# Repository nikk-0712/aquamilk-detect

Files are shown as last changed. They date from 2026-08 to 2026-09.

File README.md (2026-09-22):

# Aqua Milk Detect

**Milk purity in seconds.**

A low-cost, portable IoT + edge-ML device that classifies a milk sample as **Pure**,
**Water-adulterated**, **Detergent-adulterated** or **Starch-adulterated** — or honestly
says **Uncertain** — in a few seconds, using six sensors and an on-device SVM. It flushes
its own chamber between tests, shows the verdict on a TFT, and serves its own Wi-Fi
dashboard with no internet involved.





SDGs: 3 (Good Health), 9 (Industry & Innovation), 12 (Responsible Consumption).

---

## How the whole thing fits together

```mermaid
flowchart LR
  subgraph browser["Browser (GitHub Pages, HTTPS)"]
    FLASH["Flash<br/>ESP Web Tools"]
    CAL["Calibrate<br/>Web Serial"]
    COL["Collect<br/>Web Serial → CSV"]
  end
  subgraph device["ESP32 device"]
    S1["01_calibration"]
    S2["02_collection"]
    S3["03_deployment<br/>SVM + dashboard"]
  end
  TRAIN["training/train.py<br/>SVM + report"]

  FLASH -->|.bin| S1 & S2 & S3
  CAL <-->|JSON over USB| S1
  COL <-->|JSON over USB| S2
  COL -->|labelled CSV| TRAIN
  TRAIN -->|model.h + scaler.h| S3
  S3 -->|own Wi-Fi, HTTP| PHONE["Phone / laptop"]
```

Four stages, in order:

| Stage | You do | Where |
|---|---|---|
| 1 · Calibrate | Zero and span every sensor; constants are saved in the ESP32's NVS | [01_calibration](01_calibration/) |
| 2 · Collect | Capture labelled pure/spiked samples; the browser writes the CSV | [02_collection](02_collection/) |
| 3 · Train | Fit the SVM, read the honest report, export two headers | [training](training/) |
| 4 · Deploy | Flash the finished tester; it runs standalone | [03_deployment](03_deployment/) |

The web app that drives stages 1, 2 and the flashing lives in [web/](web/) and is
published to GitHub Pages by CI. Shared sensor code lives once in
[libs/AquaMilkSensors](libs/AquaMilkSensors) — all three firmwares compile the same file.

---

## Hardware

ESP32 DevKit V1 (38-pin, ESP32-WROOM-32), Arduino core — not ESP-IDF.

| Function | Part | Interface |
|---|---|---|
| pH | Analog pH kit, BNC probe | analog → ADC1 |
| TDS / conductivity | DFRobot Gravity Analog TDS | analog → ADC1 |
| Turbidity | Turbidity sensor + module | analog → ADC1 |
| Colour | TCS34725 RGB + Clear | I²C |
| Temperature | DS18B20 waterproof | OneWire |
| Display | 1.8" ST7735 TFT, 128×160 | SPI |
| Pump | 6 V peristaltic dosing pump | via 3.3 V relay module |
| Control | Browser dashboard (Wi-Fi) | — |
| Power | 12 V 1.5 A adapter + LM2596 buck ×2 | — |

### Pin map (final — used by all three firmwares)

Defined once in [`libs/AquaMilkSensors/src/pins.h`](libs/AquaMilkSensors/src/pins.h).

| Signal | GPIO | Notes |
|---|---|---|
| pH analog in | **36** | VP, ADC1_CH0, input-only |
| TDS analog in | **39** | VN, ADC1_CH3, input-only |
| Turbidity analog in | **34** | ADC1_CH6, input-only |
| TCS34725 SDA / SCL | **21 / 22** | I²C |
| DS18B20 data | **4** | 4.7 kΩ pull-up to 3V3 |
| TFT SCLK / MOSI | **18 / 23** | VSPI |
| TFT CS / DC / RST | **5 / 2 / 15** | DC/RST on strapping pins — pull the DevKit to flash, then reseat |
| TFT backlight | 3V3 | (GPIO32 left free for PWM dimming) |
| Pump (relay IN) | **25** | Digital output, active-HIGH |
| (GPIO27 free) | — | TTP223 touch pad removed — browser-controlled |

Free for later: 13, 14, 26, 32, 33, 35 (35 input-only). Avoid GPIO12 (boot strapping).

### Two wiring things that will bite you

**1 · The analog sensors can exceed 3.3 V.** The ESP32's ADC tops out at ~3.3 V, but the
turbidity module swings to 4.5 V and the pH board can approach 5 V. Put a **resistor
divider** (2:1 is fine, e.g. two 10 kΩ) on those channels, or run the boards from 3.3 V.
Then tell the firmware the ratio you actually built — `div_ph`, `div_turb`, `div_tds` on
the Calibrate page — because everything downstream reports millivolts *at the sensor*.
All three analog channels are on **ADC1** deliberately: ADC2 does not work while Wi-Fi is
on, and stage 3 needs Wi-Fi.

**2 · The pump is switched by a 3.3 V relay module.** It is driven straight from GPIO25 —
the module's onboard transistor and flyback do the work, so no 2N2222 level-shifter is
needed:

```
GPIO25 → relay IN      pump +6 V feed → relay COM/NO
3V3    → relay VCC
GND    → relay GND
```

This module is **active-HIGH** (GPIO HIGH = pump ON), so `PUMP_ACTIVE_LOW` defaults to
`false` in [`sensors.h`](libs/AquaMilkSensors/src/sensors.h). Got an active-LOW board (pump
runs at idle)? Set that flag `true` and rebuild. **Never PWM a relay** — drive it as a
plain digital output. A **1N4007 across the pump** (band → +6 V) is optional insurance
against contact arcing.

### Power

```mermaid
flowchart LR
  ADP["12 V 1.5 A adapter"] --> B1["LM2596 → 6 V"] --> PUMP["6 V pump<br/>1N4007 across it"]
  ADP --> B2["LM2596 → 5 V"] --> ESP["ESP32 5V pin"]
  ESP --> R3["3V3 rail"] --> SENSORS["TFT · TCS34725 · DS18B20"]
  ESP -.->|"GPIO25 → 3.3 V relay"| PUMP
```

Full connection-by-connection list and the power budget: [docs/wiring.md](docs/wiring.md).
Enclosure and test-chamber dimensions: [docs/enclosure.md](docs/enclosure.md), printable
model in [hardware/enclosure.scad](hardware/enclosure.scad).

---

## Use it

### Flash

Easiest path: open the Pages site in **desktop Chrome or Edge** → **Flash** → pick a
firmware. That is why CI exists; the `.bin` files are published next to the site. You
never tell the page a COM port — Chrome shows its own serial-device picker when you click
Install, and you choose your board there (`USB-SERIAL CH340 (COM7)` or similar). If the
board is not in that list it is a driver or cable problem: install the CH340/CP2102
driver and use a data-capable cable, not a charge-only one.

From a clone instead. Find your port first — **`COM5` below is only an example**:

```bash
arduino-cli board list
```

```bash
arduino-cli compile --fqbn esp32:esp32:esp32:PartitionScheme=huge_app --libraries libs 01_calibration
```

```bash
arduino-cli upload -p COM5 --fqbn esp32:esp32:esp32:PartitionScheme=huge_app 01_calibration
```

`--libraries libs` is what resolves `#include <sensors.h>`. Using the Arduino IDE? Copy
`libs/AquaMilkSensors` into your `Arduino/libraries/` folder once. Library and core
versions are pinned in
[`build-firmware.yml`](.github/workflows/build-firmware.yml).

### Calibrate, then collect

Walkthroughs live with the firmware: [stage 1](01_calibration/README.md),
[stage 2](02_collection/README.md). Order matters — the collection firmware reads the
constants stage 1 stored, and the model is only as good as the calibration underneath it.

### Train

```bash
python -m venv .venv
.venv/Scripts/activate  # macOS/Linux: source .venv/bin/activate
python -m pip install -r training/requirements.txt
```

```bash
python training/train.py
```

Reads `training/data/*.csv`, prints accuracy, macro-F1, per-class precision/recall, the
full confusion matrix, a threshold sweep and a limitations section, then writes `model.h`
and `scaler.h`. Copy both into `03_deployment/` and reflash. Details and the honest
reading of those numbers: [training/README.md](training/README.md).

Want to see the pipeline run before you own any data? `python training/train.py --synthetic`.

### Run the finished device

Power it. It brings up its own Wi-Fi — **AquaMilk-XXXX**, password shown on the TFT — and
serves the dashboard at **http://192.168.4.1**. It runs a **captive portal**, so the moment
your phone joins the network the "Sign in to Wi-Fi" browser pops open on the dashboard
automatically — no need to type the address. (If your phone shows it in the cut-down captive
window, tap "open in browser" for the full live view.) Point it at your own network in
Settings and it also answers at `http://aquamilk.local`.

Everything is controlled from the dashboard — **Run test**, **Flush**, **Tare**,
**Re-check calibration**, **Settings**, **Wi-Fi**, and **Factory reset**. The TTP223
touch pad and its gestures were removed, so there is no on-device menu or sleep.

A test averages ~3 s, shows the class with a confidence ring, gives the binary
pure-vs-adulterated headline plus the two sensors that drove the decision, logs the
result, then flushes for ~5 s. Below the confidence threshold (default 0.60, adjustable)
it reports **Uncertain** rather than guessing.

---

## Repo layout

```
aquamilk-detect/
├── PROJECT_CONTEXT.md      the spec; it wins any disagreement with this README
├── 01_calibration/         stage 1 sketch + walkthrough
├── 02_collection/          stage 2 sketch + capture workflow
├── 03_deployment/          stage 3 sketch, SVM inference, dashboard, model headers
├── libs/AquaMilkSensors/   shared sensors, calibration, pump, display, feature contract
├── web/                    the GitHub Pages app (+ firmware/ filled by CI)
├── training/               SVM trainer, notebook, report
├── tools/                  build_dashboard.py (gzips the device dashboard into PROGMEM)
├── docs/                   wiring detail, original build prompts
└── .github/workflows/      build firmware · deploy Pages
```

## CI

One workflow, [`build-and-deploy.yml`](.github/workflows/build-and-deploy.yml): regenerate
`03_deployment/dashboard.h` (failing if the committed copy was stale), compile all three
sketches with pinned tool/core/library versions, stage the merged `.bin`s and ESP Web
Tools manifests into `web/firmware/`, then publish `web/` to Pages. It fails loudly if any
sketch does not compile, and the job summary warns when the deployment build still carries
the placeholder model.

The binaries are **not committed** — they reach Pages as an artifact. arduino-cli pads a
merged image to the full 4 MB flash size, so committing three of them added ~12 MB to git
on every run; going via the artifact also means CI needs no write access to the repo and
leaves no bot commits. The trade-off: a plain `git clone` gives you no prebuilt binaries,
so build them yourself or grab them from the live site.

Live at **https://nikk-0712.github.io/aquamilk-detect/**. Pages is set to Source:
GitHub Actions.

## Honest limits

- `03_deployment/model.h` ships as a **placeholder**. Until you train, every test
  correctly reports "Uncertain — no model on device".
- The model learns raw sensor millivolts from *your* device with *your* calibration.
  Recalibrating, swapping a probe or moving to another board shifts those numbers.
- Starch is the hardest class — it pushes turbidity the same direction fat does.
- Specific gravity comes from grams in a fixed-volume chamber, with an approximate
  thermal-expansion correction. The constants are tunable in `sensors.cpp` and
  `training/utils.py`; they are one place real hardware will need tuning.
- This is a screening instrument, not a laboratory assay. It tells you a sample looks
  wrong and deserves a real test.

MIT licensed.

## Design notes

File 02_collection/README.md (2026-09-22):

# Stage 2 — Data collection firmware

Captures labelled training samples and streams them to the **Collect** page of the web
app, which builds the CSV in the browser. No Wi-Fi, no SD card. Sensor code and
calibration are inherited from Stage 1 — same `libs/AquaMilkSensors`, same NVS
namespace, so **calibrate before you collect**.

## Flash it

Web app: **Flash → Collection firmware** (Chrome asks which device; no port to configure).
Or, with your own port from `arduino-cli board list` in place of the example `COM5`:

```bash
arduino-cli compile --fqbn esp32:esp32:esp32 --libraries libs 02_collection
```

```bash
arduino-cli upload -p COM5 --fqbn esp32:esp32:esp32 02_collection
```

## Capture workflow

1. Open **Collect**, connect the device.
2. Fill in the labels: milk type (cow / buffalo / toned), adulterant (pure / water /
   detergent / starch), level %, and the free-text **source** (which dairy, shop or
   person the milk came from). The labels live in the browser — the device never sees
   them, it only measures.
3. Pour the sample into the chamber. Watch the live values settle.
4. Hit **Capture**. The device averages for `avg_ms` (default 3 s), emits one
   `{"t":"sample",…}` record, then auto-flushes for `flush_ms` (default 5 s) and sends
   `{"t":"flush_done"}`. One capture = one CSV row; there is no auto-batching.
5. Repeat. The browser keeps the running table, per-class counts, and the CSV export.

Capture is refused with `{"t":"ack","ok":false,"msg":"busy"}` while an average or a
flush is still running, so you cannot accidentally sample into a flushing chamber.

**Aim for balance.** The per-class counts in the web app exist because an SVM trained
on 90 pure and 6 starch samples will simply learn to say "pure". Collect across more
than one source too — a model trained on one dairy's milk mostly learns that dairy.

## Sample record fields

Names match the CSV schema (`PROJECT_CONTEXT.md` §5) exactly, so the browser maps them
straight into a row:

| Field | Meaning |
|---|---|
| `temp_c` | DS18B20 °C |
| `ph_raw_mv` | pH board output, millivolts, divider-corrected |
| `tds_raw_mv` | TDS board output, millivolts |
| `turbidity_raw_mv` | Turbidity board output, millivolts |
| `color_r`, `color_g`, `color_b`, `color_clear` | TCS34725 raw channels |
| `ph_sd`, `tds_sd`, `turbidity_sd`, `density_sd`, `temp_sd` | Standard deviation across the averaging window |
| `sg` | Derived temperature-corrected specific gravity (this is model feature 3) |
| `n` | Reads that survived outlier trimming (top/bottom 10 % dropped) |
| `ts`, `count` | Device millis, session sample counter |

The `*_sd` columns are the honest-sample check: if `density_sd` is large someone
knocked the bench, if `turbidity_sd` is large there were bubbles. Retake that sample
rather than training on it.

## Commands

| Command | Effect |
|---|---|
| `{"cmd":"capture"}` | Average, emit one sample, auto-flush |
| `{"cmd":"flush","ms":5000}` | Flush now |
| `{"cmd":"tare"}` | Re-zero the empty chamber |
| `{"cmd":"set","key":"avg_ms","val":3000}` | Averaging window (200–20000 ms) |
| `{"cmd":"set","key":"flush_ms","val":5000}` | Flush duration (0–60000 ms) |
| `{"cmd":"reset_counter"}` | Clear the on-device session counter |

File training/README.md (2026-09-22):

# training/ — SVM trainer

Turns the CSVs you collected into `model.h` + `scaler.h` for the deployment firmware,
plus an evaluation report you can defend in a viva.

## Run it

```bash
python -m venv .venv
.venv/Scripts/activate  # macOS/Linux: source .venv/bin/activate
python -m pip install -r training/requirements.txt
```

Put the CSVs exported from the web app's **Collect** page into `training/data/`, then:

```bash
python train.py
```

Smoke-test the whole pipeline before you own any real data:

```bash
python train.py --synthetic
```

Check the maths itself (feature transform + the probability path the firmware runs):

```bash
python utils.py
```

Useful flags: `--chamber-ml` (must match the value stored on the device — the Calibrate
page shows it), `--test-size`, `--seed`, `--min-per-class`, `--no-export`.

## What comes out

| File | What it is |
|---|---|
| `model.h` | The trained SVM: support vectors, dual coefficients, intercepts, Platt `probA_`/`probB_` |
| `scaler.h` | `FEAT_MEAN[9]`, `FEAT_SCALE[9]`, and the recommended `CONF_THRESHOLD` |
| `report/report.txt` | The whole run as text: CV score, held-out metrics, confusion matrix, threshold sweep, limitations |
| `report/confusion.png` | Confusion matrix |
| `report/threshold.png` | Accuracy vs coverage as the Uncertain cut-off moves |
| `report/metrics.json` | Every number, machine-readable |
| `pipeline.joblib` | Fitted scaler + model, if you want to keep exploring in Python |

Copy the two headers into the firmware and reflash:

```bash
cp training/model.h training/scaler.h 03_deployment/
```

Pushing those changed headers re-triggers the firmware build in CI, so the `.bin` the
web app offers gets your model automatically.

## Features

Exact order, matching `libs/AquaMilkSensors/src/features.h`:

```
[ph, tds, turbidity, temperature, color_r, color_g, color_b, color_clear]
```

`raw_to_features()` in `utils.py` is the single definition of that mapping. It does no
transforms: every feature is fed as the raw millivolts, temperature and raw colour
counts the CSV already holds. (The density/load-cell feature was removed.)

That is a deliberate choice. The CSV only stores raws, so training on raws means the
firmware and the trainer cannot disagree about what a feature *is*, and re-calibrating
the pH probe does not silently invalidate a trained model. `StandardScaler` makes the
units irrelevant to the SVM anyway. Calibrated pH / ppm / NTU still exist on the device —
for humans to read, not for the model to consume.

## Why not micromlgen

The spec suggested `micromlgen.port()`. Its SVM port emits `predict()` only, and this
product needs a **probability**, because anything below the confidence threshold has to
come out as "Uncertain". A model that can only say "starch" with no confidence attached
cannot implement that rule.

So the exporter writes scikit-learn's own `SVC` internals, and
`03_deployment/svm_infer.h` runs libsvm's actual procedure: one-vs-one decision values →
Platt sigmoids → Chu & Lin pairwise coupling. Before writing `model.h`,
`verify_probabilities()` re-implements that same path in numpy and asserts it reproduces
`clf.predict_proba` (typically within ~2e-3, the coupling loop's own tolerance). If it
ever disagrees, the run fails and nothing is exported — a wrong confidence would be
worse than no model, since the whole Uncertain mechanism rests on it.

## Reading the report honestly

- **Report the confusion matrix, not the accuracy.** With a few dozen rows per class,
  accuracy moves several points just from reshuffling the split.
- **Starch is the hard class.** It pushes turbidity the same direction fat does, so it
  gets confused with pure milk more than water or detergent do. If starch recall is much
  worse than the rest, that is the expected failure, not a bug.
- **Balance matters more than volume.** The trainer warns when one class is more than
  3× another, and when every row shares a single `source` or `milk_type` — a model
  trained on one dairy mostly learns that dairy.
- **The binary headline** (pure vs adulterated) is always reported alongside the
  4-class numbers, because it is the number a user actually acts on.
- `--synthetic` runs are labelled as synthetic in both the console output and
  `metrics.json`. Those numbers describe a random generator, not milk.

## data/

`SYNTHETIC_sample.csv` is generated, clearly marked, and exists so `python train.py`
works on a fresh clone. Delete it once you have real data — otherwise it will be
concatenated into your dataset and quietly train on invented numbers.

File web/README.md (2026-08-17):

# web/ — the GitHub Pages app

Static single-page app: **Home · Flash · Calibrate · Collect · Run**. No build step, no
bundler, no backend — the files here are exactly what gets served.

```
web/
├── index.html                 all five sections
├── app.js                     routing + Calibrate/Collect logic
├── serial.js                  Web Serial transport for the §8 JSON protocol
├── app.css                    the app's styles
├── design/tokens.css          shared design variables (the device dashboard mirrors these)
├── logo.svg                   the mark
└── firmware/                  .bin files + ESP Web Tools manifests (CI fills these)
```

## Run it locally

Web Serial and browser flashing need a **secure context**, and `localhost` counts:

```bash
python -m http.server 8000 --directory web
```

Then open <http://localhost:8000>. Opening `index.html` as a `file://` URL will not work —
ES modules and Web Serial both refuse that.

## What needs what

| Page | Needs |
|---|---|
| Home, Run | Any browser, any device |
| Flash | Desktop Chrome/Edge + HTTPS (or localhost) — ESP Web Tools |
| Calibrate, Collect | Desktop Chrome/Edge + HTTPS (or localhost) — Web Serial |

The app detects a missing Web Serial API and says so on the Home page rather than
failing silently when you click Connect.

## firmware/

`*-manifest.json` point at `calibration.bin`, `collection.bin`, `deployment.bin`. The
[build-and-deploy workflow](../.github/workflows/build-and-deploy.yml) compiles all three
sketches, drops the **merged** binaries here (merged = bootloader + partition table + app
in one image, which is why the manifest offset is 0), stamps the real version into the
manifests, and ships the folder to Pages as an artifact.

The `.bin` files are deliberately **not in git** — each is 4 MB of padded flash image, so
committing them cost ~12 MB per CI run. That means a fresh clone has manifests pointing at
binaries that only exist on the deployed site: serving `web/` locally will show the Flash
buttons, but they cannot install until you either run the workflow or build locally and
copy the merged `.bin`s in yourself.

## Notes on the code

- **No localStorage.** Collected rows live in a JavaScript array and leave via the
  Export CSV button. Reloading the tab loses unexported rows — that is deliberate;
  half-finished datasets silently resurrecting is worse.
- **CSV columns** are built in `app.js:COLUMNS`, matching `PROJECT_CONTEXT.md` §5 exactly
  so the Python trainer can read the file with no massaging.
- **Two independent serial links**, one per page. Calibrate and Collect run different
  firmwares, so there is no case where both are connected to the same device at once.
- **esp-web-tools is vendored**, not loaded from a CDN: `web/vendor/esp-web-tools/`
  holds v10.4.0's bundled `dist/web` (Apache-2.0, `LICENSE` included). It started as a
  pinned unpkg URL, which broke the Flash page twice over — the pinned version did not
  exist, and a CDN fetch is blockable by extensions. Nothing external is fetched now.
  To update: `npm pack esp-web-tools@<version>`, then copy `dist/web/*.js` + `LICENSE`
  into that folder.
- **The Run page is a launcher, not a dashboard.** This site is HTTPS; the device serves
  plain HTTP on a private IP, and browsers block that mix. So the live dashboard lives on
  the device (`03_deployment/dashboard.html`) and shares this app's design tokens.

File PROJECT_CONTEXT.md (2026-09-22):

# Aqua Milk Detect — PROJECT CONTEXT (single source of truth)

> Every agent building any part of this project MUST read this file first and treat it as authoritative. If a prompt and this file disagree, this file wins. Keep the same names, pins, colors, and schema everywhere.

**Tagline:** *Milk purity in seconds.*
**One line:** A low-cost, portable IoT + edge-ML device that classifies a milk sample as **Pure / Water-adulterated / Detergent-adulterated / Starch-adulterated** (or **Uncertain**) in seconds, using multi-sensor data and an on-device SVM, with a self-cleaning flush and an elegant web + on-device UI.

SDGs: 3 (Good Health), 9 (Industry/Innovation), 12 (Responsible Consumption).

---

## 1. System overview (three stages, one repo)

The system is delivered as **three separate Arduino firmwares** plus **one web app**, **one Python trainer**, and **CI to build + host**:

| Stage | Folder | Runs on | Talks to browser via | Purpose |
|---|---|---|---|---|
| 1. Calibration & test | `01_calibration/` | ESP32 | **USB Web Serial** | Read + calibrate each sensor and all-at-once |
| 2. Data collection | `02_collection/` | ESP32 | **USB Web Serial** | Capture labelled samples → CSV in browser |
| 3. Deployment | `03_deployment/` | ESP32 | **Wi-Fi (SoftAP / STA)** + TFT | Run the trained SVM, show verdict, self-flush |
| Web app | `web/` | GitHub Pages | — | Flash firmware + Calibrate + Collect UIs |
| Trainer | `training/` | User PC (Python) | — | Train SVM from CSV → export `model.h` |
| CI | `.github/workflows/` | GitHub Actions | — | Build `.bin`s + deploy `web/` to Pages |

**Data/ML loop:** Stage 2 collects labelled CSV → Python trainer makes `model.h` → drop into Stage 3 → deploy.

---

## 2. Hardware (FINAL bill of materials)

**MCU:** ESP32 DevKit V1, 38-pin, ESP32-WROOM-32 (user owns). Framework: **Arduino (arduino-esp32 core)**. NOT ESP-IDF.

**Sensors & modules:**
| Function | Part | Interface | Notes |
|---|---|---|---|
| pH | Analog pH sensor kit (Industrial Grade Analog pH, BNC probe) | Analog → ADC1 | Detergent (alkaline) flag; output may reach ~3–5 V → **see ADC note** |
| TDS / conductivity | DFRobot Gravity Analog TDS (genuine) | Analog → ADC1 | Water/detergent dilution; library `GravityTDS` |
| Turbidity | Turbidity Sensor With Module | Analog → ADC1 | Starch/suspended solids; output 0–4.5 V → **needs divider** |
| Colour | TCS34725 RGB+Clear | I²C | R,G,B,Clear channels as features |
| Temperature | DS18B20 waterproof (genuine chip, 1 m) | OneWire | Temp compensation for pH/TDS/density |
| Display | 1.8" TFT ST7735, 128×160 | SPI | On-device verdict + status |
| Pump | 6 V peristaltic dosing pump | via relay | Auto-flush chamber with distilled water |
| Pump switch | **3.3 V relay module** (user owns) | GPIO (digital) | Driven direct from GPIO25 — see §4 |
| Flyback | 1N4007 diode (optional) | across pump | Cheap insurance against contact arcing |
| Power step-down | LM2596 buck | — | 12 V → 6 V (pump) and 5 V/3.3 V (logic) |
| Power source | 12 V 1.5 A adapter (user owns) | — | 18 W, ample |
| Control | **Browser dashboard** over Wi-Fi | — | No touch pad, no LEDs |
| Fluidics | Silicone tube 1 m + user's reservoir & waste cup | — | Flush plumbing |

**User-owned / not purchased:** ESP32, 3.3 V relay module, 12 V 1.5 A adapter, 1N4007 diode (optional), jumper wires, breadboard.
**User to source separately:** enclosure + test chamber, distilled water, (optional, cheap) pH 4/7 buffer sachets.

**Purchase split (both free-shipping > ₹999, ₹0 shipping):**
- **Robu.in:** pH kit (₹1,975) + DS18B20 genuine-chip (₹89).
- **Robocraze:** DFRobot TDS, turbidity, 6 V pump, TCS34725, 1.8" TFT, LM2596, silicone tube.
- Total to buy ≈ **₹4,969** (under ₹5,000 budget). Owned parts saved ≈ ₹600.

---

## 3. Pin map (ESP32-WROOM-32, 38-pin) — FINAL

Use these exact pins in all firmwares.

| Signal | GPIO | Notes |
|---|---|---|
| pH analog in | **36** (VP, ADC1_CH0) | input-only, ADC1 |
| TDS analog in | **39** (VN, ADC1_CH3) | input-only, ADC1 |
| Turbidity analog in | **34** (ADC1_CH6) | input-only, ADC1 |
| TCS34725 SDA | **21** | I²C |
| TCS34725 SCL | **22** | I²C |
| DS18B20 data | **4** | OneWire + 4.7 kΩ pull-up to 3V3 |
| TFT SCLK | **18** | VSPI |
| TFT MOSI | **23** | VSPI |
| TFT CS | **5** | strapping pin — fine as output |
| TFT DC | **2** | strapping pin — pull the DevKit from its socket to flash, then reseat |
| TFT RST | **15** | strapping pin — pull the DevKit from its socket to flash, then reseat |
| TFT BL (backlight) | tie to 3V3 (or **32** for dim) | |
| Pump (relay IN) | **25** | Plain digital output (active-HIGH) |
| (GPIO27 free) | — | TTP223 removed — device controlled from the browser |

**ADC rules (critical):**
- All three analog sensors are on **ADC1** because **ADC2 is unusable while Wi-Fi is on**.
- ESP32 ADC is 12-bit, 0–3.3 V. **Any sensor board that can output > 3.3 V (turbidity 0–4.5 V; pH board can approach 5 V) MUST go through a resistor voltage divider** (e.g. 2:1) or the board must be run at 3.3 V. Document the divider in the wiring README. Calibration maps raw ADC → sensor value, so exact divider ratio is captured during calibration.
- Use `analogReadMilliVolts()` / attenuation `ADC_11db` for the widest linear range; average many samples.

Free/unused pins for future use: 13, 14, 26, 33, 35 (35 input-only). Avoid GPIO12 (strapping, boot).

---

## 4. Power & pump switching (3.3 V relay)

Power: 12 V adapter → LM2596 #1 set to **6 V** for the pump; logic runs from **5 V/USB or a second LM2596 at 5 V**. ESP32 from 5 V pin or USB.

Pump switching uses a **3.3 V relay module** driven straight from the ESP32 — the module's onboard driver transistor and flyback do the work, so GPIO25 sources almost no current and no level-shifter is needed. Firmware therefore:
- Drives the pump as a **plain digital output on GPIO25** (`pinMode(OUTPUT)` + `digitalWrite`). **Never PWM a relay** — the coil would chatter. Pump control is on/off only.
- Uses a `PUMP_ACTIVE_LOW` compile-time flag for the module's polarity. **This build's module is active-HIGH (GPIO HIGH = pump ON), so the flag defaults to `false`.** For the common opto-isolated boards that energize on LOW, set it `true`.
- Wiring: `GPIO25 → relay IN`, `3V3 → relay VCC`, `GND → relay GND`, and the pump's +6 V feed through the relay `COM`/`NO` contacts. A **1N4007 across the pump** (band → +6 V) is optional insurance against contact arcing.

---

## 5. Data schema (CSV) — FINAL

One captured sample = one CSV row. Store **raw** sensor values (so features can be re-derived) plus labels & metadata.

```
timestamp_iso, milk_type, adulterant, level_pct, source,
temp_c, ph_raw_mv, tds_raw_mv, turbidity_raw_mv,
color_r, color_g, color_b, color_clear
```

- `milk_type` ∈ {cow, buffalo, toned}
- `adulterant` ∈ {pure, water, detergent, starch}
- `level_pct` ∈ {0, 5, 10, 20, 30, …} (0 for pure)
- `source` = free text (dairy / shop / person / place) — **user's tagging field**
- `*_raw_mv` = averaged ADC millivolts; color_* = TCS34725 channels.
- CSV is created and saved **in the browser** (no server, no SD card).

**Feature vector for the model (≈10):** `ph, tds, turbidity, density(temp-corrected specific gravity), temperature, color_r, color_g, color_b, color_clear` (+ optionally derived ratios). Fit a `StandardScaler`; export scaler constants alongside the model.

---

## 6. Model & inference

- **Algorithm:** SVM (scikit-learn). Compare **linear vs RBF** via `GridSearchCV` + stratified k-fold; pick best by macro-F1.
- **Classes:** `pure, water, detergent, starch`. Also compute a **binary headline** (pure vs adulterated).
- **Uncertain / reject:** use `predict_proba` (Platt) — if top-class probability `< threshold` (default **0.60**, tunable in the deployment Settings), output **Uncertain**. Optionally a one-class outlier guard on "pure".
- **Export:** `micromlgen` → `model.h` (C++), plus a `scaler.h` (means/scales) → included by `03_deployment`. Inference on-device is microseconds.
- **Honesty:** trainer must print accuracy, macro-F1, full **confusion matrix**, per-class precision/recall, and note that starch is the hardest class. Report both multiclass and binary numbers.

---

## 7. Interaction — browser dashboard (deployment)

**No touch pad, no LEDs.** All control and feedback is on the **TFT** (status + verdict) and the **web dashboard** served over Wi-Fi. Dashboard controls: **Run test**, **Flush**, **Tare**, **Re-check calibration**, **Settings** (threshold / flush ms / avg ms), **Wi-Fi**, and **Factory reset**.

Test flow: sample in → **Run test** on the dashboard → TFT shows "Reading…" (average ~3 s) → verdict + confidence → **auto-flush ~5 s** → ready. Uncertain → amber "Uncertain — retest".

---

## 8. Connectivity & protocol

- **USB Web Serial (Stages 1 & 2):** newline-delimited **JSON**. Baud 115200.
  - Device→browser: `{"t":"reading","ph":..,"tds":..,"turb":..,"temp":..,"dens":..,"r":..,"g":..,"b":..,"c":..,"ts":..}`
  - Browser→device: `{"cmd":"capture"}` · `{"cmd":"calibrate","sensor":"ph","point":7.0}` · `{"cmd":"tare"}` · `{"cmd":"flush","ms":5000}` · `{"cmd":"set","key":"..","val":..}`
  - Device acks: `{"t":"ack","cmd":"..","ok":true,"msg":".."}`
- **Wi-Fi (Stage 3):** default **SoftAP** SSID `AquaMilk-XXXX` (XXXX = last 2 bytes of MAC), password shown on TFT; device serves its own dashboard at `http://192.168.4.1` with a **WebSocket** for live data. Optional **STA** (join lab Wi-Fi, creds set in Settings) reachable at **`aquamilk.local`** via mDNS. HTTP only on-device (that's why Run is device-served — an HTTPS page can't call an HTTP device: mixed content).

---

## 9. Design language (Apple-grade) — shared by web app AND device dashboard

**Use the installed Apple design skill for all UI work.** Both the GitHub-hosted app and the ESP32-served Run page share this system.

- **Type:** `-apple-system, "SF Pro Text", "SF Pro Display", system-ui, sans-serif`. Big rounded titles, strong hierarchy, tight tracking on large text.
- **Theme:** **light + dark, auto (`prefers-color-scheme`), default light.**
- **Palette:**
  - Accent (aqua-teal): `#0FB5C9` (darker `#0A8FA3`)
  - Backgrounds: light `#F5F5F7`, dark `#000000` — Apple's own neutrals; they read warmer
    and calmer than the blue-tinted `#F5F7FA` / `#0B0F14` this started with
  - Text: light `#1D1D1F`, dark `#F5F5F7`; secondary `#86868B` / `#A1A1A6`
  - Cards/surfaces: light `#FFFFFF`, dark `#1D1D1F`, with subtle translucency/blur (frosted) where tasteful
  - **Result semantics:** Pure = green `#34C759` · Adulterated = red `#FF3B30` · Uncertain = amber `#FF9F0A` (Apple system colors)
- **Shape & motion:** 16–20 px corner radius, soft layered shadows, 8-pt spacing grid, 200–300 ms ease transitions, gentle spring on the result reveal, circular **confidence ring** (SVG). SF-style segmented controls, toggles, large tap targets.
- **Tone:** calm, spacious, confident. No clutter, no debug vibes. Production-grade.
- **Branding:** title **"Aqua Milk Detect"**, tagline **"Milk purity in seconds"**, a **minimal logo mark** (agent designs it — think a clean drop/wave in aqua-teal). Provide as inline SVG.
- **Device dashboard constraint:** must be lean enough to live in ESP32 flash (single gzipped HTML/CSS/JS in PROGMEM or LittleFS) yet visually identical in spirit.

---

## 10. Repo layout (created by CI prompt)

```
aquamilk-detect/
├── PROJECT_CONTEXT.md          ← this file (source of truth)
├── README.md                   ← wiring, setup, usage, wiring diagram
├── 01_calibration/             ← Arduino sketch
├── 02_collection/              ← Arduino sketch
├── 03_deployment/              ← Arduino sketch (+ model.h, scaler.h, web assets)
├── web/                        ← the GitHub-Pages SPA (Flash/Calibrate/Collect/Run)
│   └── firmware/               ← .bin + ESP Web Tools manifests (built by CI)
├── training/                   ← Python trainer (notebook + script) → model.h
├── docs/                       ← diagrams, images
└── .github/workflows/          ← build + deploy
```

## 11. Global conventions
- License **MIT**.
- Each sample/test **averages ~3 s** of readings. Auto-flush default **5 s** (adjustable in Settings).
- Confidence threshold default **0.60** (Settings).
- Store calibration constants + settings + rolling log in **NVS (`Preferences`)**; larger logs/assets in **LittleFS**.
- Persistent rolling test log kept on device flash (last ~200 results), plus full session history in the browser (exportable CSV).
- Prompts assume a capable coding agent (files + shell + arduino-cli/PlatformIO + Git/GitHub + skills). Target boards/libs pinned by CI.
- Web Serial + ESP Web Tools work in **desktop Chrome/Edge only** (state this in the app UI).

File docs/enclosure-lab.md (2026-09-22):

# Enclosure — bench instrument

Model: [`hardware/enclosure-lab.scad`](../hardware/enclosure-lab.scad). This is a separate
file and a separate design; it does not replace `hardware/enclosure.scad`.

**140 W × 200 D × 320 H mm.** One prism, superellipse corners, a control facet cut off the
front-top edge at 30°, and three labelled things you touch.

---

## Where everything goes

Every point you interact with is engraved into the surface beside it, so the machine tells
you what it wants without a manual.

| Label | Where | What goes there |
|---|---|---|
| **MILK** | Front, middle band — the big drawer | The sample cup. Pull the drawer out, stand the cup in the round pocket, fill it, push it back in |
| **DISTILLED WATER** | Top surface, behind the round carriage | The flush tank, ~450 mL. Unscrew the cap marked WATER and pour in |
| **WASTE** | Front, bottom band — the shallow tray | Nothing goes *in*. Pull it out and empty it when the rinse water builds up |

Nothing else on the outside opens. The rear carries the power jack and the USB port on one
centreline; the sides carry one vent band each; the underside is the air intake.

**The screen** sits behind the dark panel on the angled facet, with the touch pad below it
behind the same panel. Both are invisible until the display lights. The facet is angled
because a bench instrument is read from above, and the ST7735 is a TN panel — mounted
vertical it washes out at exactly the angle you stand at.

---

## The one thing that isn't obvious

**Lift the round carriage on top before you pull the drawer.**

The probes hang about 100 mm down into the cup. The cup physically cannot slide out past
them, so something has to separate vertically first. The carriage is a plug that slides
straight up in its socket: down, it sits flush and the machine is a closed box; up, the
probes clear the cup and the drawer is free.

If the drawer feels stuck, the carriage is still down. It is the only interlock in the
machine, and it is a mechanical one.

---

## Running a test

1. **Lift** the carriage on top.
2. **Pull** the MILK drawer out.
3. **Stand the cup** in the pocket and fill it with your sample. Fill past the weir hole in
   the cup wall — the excess runs out, and that overflow is what makes the volume
   repeatable. `MAX 175 mL` is engraved on the drawer beside the pocket.
4. **Push** the drawer in. The cup rides up a 2 mm chamfer onto the fixed platform and settles
   there.
5. **Lower** the carriage. The probes enter the sample to a fixed depth.
6. **Run a test** from the dashboard. Read the verdict.
7. **Lift, pull, take the cup out, empty and rinse it by hand.**
8. **Push the empty drawer back in, lower the carriage, run the rinse.** Water from the tank
   runs over the probes and falls through the drawer's drain into the WASTE tray.

The rinse is a **probe rinse, not a cup flush** — you wash the cup at the sink. That is
deliberate: a cup that cannot drain can only be diluted, and 5 s of pumping removes about
5 % of the milk in it. Washing by hand removes 100 %.

---

## Cleaning

- **Between samples** — hand-wash the cup, run one probe rinse.
- **Daily** — lift the carriage right out and wash the probes properly. Milk leaves a protein
  and fat film that water alone will not lift, and it lands on the turbidity body's optical
  gap and the pH bulb, where it stops being hygiene and becomes sensor drift. Wipe the colour
  window in the left wall. Empty and rinse the WASTE tray.
- **Idle** — cap the pH bulb in storage solution. It must never dry out.

> **Never clean with detergent unless you can prove you rinsed it out.** Detergent is one of
> the four classes this device exists to detect, and a residue film reads as a
> detergent-adulterated sample — convincingly.

**Check your own cleaning with the instrument.** Fill the cup with distilled water and run a
normal test: TDS should fall to its distilled baseline, turbidity to clear, pH near 7 and
settling quickly rather than crawling. If not, something is still dirty.

---

## Parts and printing

Nine printed parts, largest footprint 140 × 200 — a 220 mm bed covers all of them, and none
needs supports.

| Part | Orientation |
|---|---|
| `base` | as rendered, open side up |
| `bay` | as rendered — its front is open by design, the drawer face fills it |
| `head` | **upside down**, so the facet prints as a receding wall |
| `carriage` | as rendered |
| `sample_drawer`, `waste_tray` | as rendered, open side up |
| `platform` | flat. 6 perimeters, 60 % infill — a flat, rigid rest for the cup |
| `tank_cap` | flat |

```bash
openscad -o head.stl -D 'part="head"' hardware/enclosure-lab.scad
```

Engravings are recessed 0.5 mm, never raised: raised text wears at the high points and traps
milk in its corners, while a recess just holds a shadow line and wipes clean. Cap height is
5.5 mm, the smallest a 0.4 mm nozzle holds cleanly.

Not printed: the cup (acrylic tube, ⌀70 ID × 105, with a ⌀6 weir hole drilled 45.5 mm above
the inside of its floor), the dark facet panel, the colour window, magnets,
silicone tube, fasteners.

---

## Still open

- **The rinse pump is not in the firmware.** Nothing sequences it; the tank, pump and nozzle
  are enclosure features only.
- **`turb_body_d` is the riskiest number in the model.** Measure your turbidity sensor before
  printing: it sets the cup bore, the bore sets the cup, and the cup sets the width of the
  whole instrument.
- **The carriage has no detent yet.** It slides and seats, but nothing holds it up while you
  work — today you hold it, or rest it at the top of its travel.

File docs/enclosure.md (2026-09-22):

# Enclosure

The enclosure is not a box to hide the wiring in. Two of the features the model uses —
colour and turbidity — are really *mechanical* measurements, and the enclosure is what
makes them repeatable. Get the light shrouding wrong and no amount of retraining fixes it.

The printable model is [`hardware/enclosure.scad`](../hardware/enclosure.scad). Every number
below is a variable at the top of that file, and the file is the one to trust if the two ever
disagree. Render a part with:

```bash
openscad -o body.stl -D 'part="body"' hardware/enclosure.scad
```

---

## 1. Form

**A single squircle tower with a telescoping column — 126 × 136 × 220 mm, 286 mm to the top
of the cap.** That is 3.8 L against the previous revision's 12.4: seventy percent smaller,
because the electronics moved *under* the cup instead of sitting beside it. That change also
deleted the two-shell split, and with it every seam that used to run up the sides.

Every external profile is a superellipse — `|x/a|⁵ + |y/b|⁵ = 1` — not a circular fillet.
This is the whole difference between a squircle and a rounded rectangle: a circular fillet is
only G1 continuous, so curvature jumps from zero to 1/r at the tangent point, and that
discontinuity shows up as a hard line in the highlight. A superellipse's curvature varies
continuously, so the highlight sweeps across the corner without a break. The top plate carries
the same treatment vertically — a G2 shoulder built from a superelliptic profile in Z — so the
flat top meets the side wall the way the corners do.

The fascia recess and the drawer front are squircles too. A rounded-rectangle window cut into
a squircle body is the tell of a language copied rather than understood.

### What is open to the outside — the complete list

| Opening | Where | Label |
|---|---|---|
| Pour dish | top of the column cap | **MILK**, engraved 0.4 mm |
| Tank neck | top plate, rear | **DISTILLED WATER**, engraved 0.4 mm |
| Drawer aperture | front | — |
| USB-C | rear, centred | — |
| Intake slots | underside only | — |

That is everything. No screw appears on any exterior surface: four magnets hold the top
plate, three hold the cap, and a locating lip does the aligning.

> **If the preview looks full of holes, it is the preview.** OpenSCAD's F5 view shows
> backfaces in green and draws the fascia mock as a translucent panel, so you are looking
> straight through the front at the ribs, bosses and ledges behind it. Press F6, or export an
> STL, and the body is a closed shell.

Engravings are recessed rather than embossed: raised text wears at the high points and traps
milk in its corners, while a 0.4 mm recess just holds a shadow line and wipes clean.

---

## 2. The vertical stack

```
      ╭───────╮   286   cap · MILK dish
      │COLUMN │        lifts 55 mm — it is its own piston
      │ probes│
  ┌───┴───────┴───┐  220   top plate · DISTILLED WATER neck · G2 shoulder
  │   cup 85 mL   │  178   cup rim
  │───────────────│  121   drawer plate — pull, dump, push back
  │  cup platform │
  │───────────────│   75   drop-in shelf carries the platform
  │ tank · pump   │        486 mL tank against the rear wall
  │ boards · USB  │
  └───────────────┘    0   undercut base, 6 mm tall, stepped in 3 mm
   ◄───── 126 ─────►
```

---

## 3. Cup, bore and dose

**The bore is set by the probes, never by the volume.** The turbidity body has to sit *in* the
sample, and the pH probe has to fit the annulus beside it, with real plastic between them:

```
bore ≥ turb_body_d + 2 × (ph_probe_d + 2×probe_gap + 2×rib_min)
 67  ≥ 35         + 2 × (12         + 1.2         + 2.4)
```

⌀62 is the arithmetic minimum and leaves 0.3 mm of rib. It is not buildable. At **⌀67** the
ribs come out at 1.6 mm inside and 1.2 mm outside, and the script echoes both on every render.

**Dose 85 mL** → 24.1 mm of fill → **19.1 mm of pH immersion**. That is deliberately near the
floor: most pH probes only strictly need the bulb and reference junction covered. It is the
one number in this design with no margin, so check pH settling time during calibration before
committing to it.

(The cup volume no longer feeds any measurement — density was removed — so the exact
fill level only matters for keeping the probes submerged.)

---

## 4. How you use it

1. Pour the sample into the **MILK** dish on the cap. It runs down a duct into the cup.
2. Run a test from the dashboard.
3. After the verdict: lift the column, pull the drawer, tip the cup out, push it back. The
   pump then rinses the probes with distilled water.

Pushing the drawer home walks the cup up a 1.5 mm chamfer onto the fixed platform, so at
rest it sits on the platform with 4 mm of clearance all round.

### Why the column has to move

The probes hang *into* the cup, so the cup cannot slide out horizontally past them —
something has to separate vertically first. Making the column its own piston is the smallest
mechanism that does it: one sliding part, no linkage.

The cap is keyed by three magnets on a deliberately **asymmetric** triangle. Three magnets at
120° would let it seat three ways, and only one of those puts the pour duct over the fill slot.

---

## 5. Water, waste and cleaning

**One pump, fill only.** It draws from the 486 mL internal tank and discharges over the probes
into the cup. Its job is rinsing the sensors, not emptying the machine — you empty the machine
by pulling the drawer. There is no drain pump, no dip tube and no vent hole, because the pour
dish vents.

**Between samples:** tip the cup, then one pump rinse. Because you dump the cup rather than
diluting it, a rinse only has to clear films off the probes — about 60 mL, so a tank lasts
roughly eight tests. (Diluting instead of dumping is what makes flushing expensive: a chamber
that cannot empty clears as `C₀·e^(−V/vol)`, needing three volumes of water to reach 5 %.)

**Daily:** cup out, warm water and a soft brush. Milk leaves a protein and fat film water
alone will not lift, and that film sits on the turbidity body's optical gap and on the pH
bulb, where it stops being hygiene and becomes sensor drift. Wipe both, plus the colour
window.

> **Never clean with detergent unless you can prove you rinsed it out.** Detergent is one of
> the four classes this device exists to detect, and a residue film reads as a
> detergent-adulterated sample — convincingly.

**The blank check.** Fill with distilled water and run a normal test. TDS should fall back to
its distilled baseline and turbidity to clear; pH should sit near 7 and settle quickly rather
than crawling. The sensors are the honest instrument for judging your own cleaning.

**Idle:** the pH bulb must never dry out. Lift the column off and cap the probe in storage
solution.

---

## 6. The rules that actually matter

1. The cup seats on the platform when the drawer closes. The drawer's ⌀78 hole clears the ⌀70
   platform by 4 mm all round — keep that gap clear of wires and dried-milk drips so the cup
   walks on cleanly.
2. The platform is bolted to the shelf pedestal, not clipped — two M4 bolts, heads internal.
   Print the shelf at 6 perimeters and 60 % infill so the cup sits on a rigid, flat rest.
3. The colour sensor stays dry, behind a glued acrylic window in the side wall, looking at the
   cup through a hood. Paint the interior matt black — ambient light landing on it rides
   straight into four of the model's features and changes with the time of day.

---

## 7. Power

One port means USB-C, and USB-C means a decision. Wi-Fi peaks near 500 mA on 3V3 and the pump
adds a few hundred more, so plain 5 V from a laptop port is marginal. Use a **USB-C PD trigger
board (≈₹150) set to 9 V**, feeding one LM2596 at 6 V for the pump and a second at 5 V for
logic. **Set both converters before assembly** — their trimpots are no longer reachable, which
is the price of a clean rear face.

---

## 8. Materials

Matte PETG. Not PLA — it does not survive repeated cleaning and warm rinse water.
Print visible faces at 0.10–0.12 mm: a squircle only reads as a squircle when the
layer lines disappear into the curve.

The cup and the tank hold liquid — 5 perimeters each, and run a silicone bead on the tank's
lid seam. An unsealed printed tank weeps, quietly, into the electronics beneath it.

Bought separately: ⌀6 × 3 N35 magnets (7), 2 mm smoked acrylic for the fascia (~102 × 78), a
small acrylic offcut for the colour window, four M4 bolts and nuts, silicone tube.

---

## 9. Assembly order

1. Print and dry-fit the body, shelf and drawer. Check the drawer runs freely and the cup
   walks onto the platform as it closes.
2. Bolt the platform onto the shelf pedestal, and check the shelf is seated on its ledge so
   the cup walks on squarely as the drawer closes.
3. Base: tank and lid sealed and leak-tested with water **before** anything electrical goes
   near them. Then pump, converters, PD trigger.
4. Boards on the shelf, display behind the fascia, USB-C aligned to its cutout.
   Confirm stage-1 firmware boots before adding sensors one at a time, per
   [wiring.md](wiring.md).
5. Probes into the column carrier, cables down through the cable exit, with a service loop
   long enough for 55 mm of column travel.
6. Fill the tank, run *Flush test* dry, then with water, and check nothing wets the shelf.

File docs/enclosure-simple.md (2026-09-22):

# Enclosure — the working box

Model: [`hardware/enclosure-simple.scad`](../hardware/enclosure-simple.scad). Separate file;
it does not replace `enclosure.scad` or `enclosure-lab.scad`.

**232 × 178 mm footprint. Wet bay 161 tall, dry bay 95.** Five printed parts, no supports,
body prints in one piece on a 256 bed.

The wet bay is 112 mm wide for a ⌀76 cup — **18 mm of finger clearance per side**. That is
not slack, it is the requirement: you lift a full cup of milk out of it on every test, and
with only the 8 mm the cup itself needs, you physically cannot grip it.

No styling and no mechanism — this exists to be built once, installed easily, and lived with.

---

## What goes where

```
   ┌──────────────┐
   │   WET BAY    │ 161 tall            ┌──────────────────┐
   │  cup on a    │                     │     DRY BAY      │ 95 tall
   │  fixed       │                     │ perfboard on     │
   │  pedestal    │   ← partition →     │ rails, pump      │
   │  nozzle on   │                     │ underneath       │
   │  rear wall   │                     │ TFT front        │
   │  floor = drip│                     │ USB + 12 V rear  │
   └──────────────┘                     └──────────────────┘
```

The partition is full height and solid. The **sensor wires** cross it — the colour chip's
I²C pair, the three analog probes and the DS18B20 — through two ⌀16 glands at z = 75, plus
the feed tube at z = 68.

Those heights are not arbitrary. A full 175 mL sample dumped on the wet floor pools about
**11 mm** deep, so every crossing sits far above it. They are also *below* the dry bay's
ceiling at 95 — the partition keeps rising past the dry bay to full wet height, so anything
placed higher would open into open air instead of into the electronics bay.

---

## The four files

| File | What it is |
|---|---|
| `body.stl` | The tray. Both bays, the partition, the cup pedestal, the perfboard rails, and every cutout. The only big print |
| `wet_lid.stl` | Probe carrier. Holds the four probes, lifts off by its two rails |
| `dry_lid.stl` | Cover over the electronics. Snaps on, no tools |
| `platform.stl` | The disc the cup stands on. Bolts to the top of the pedestal |

(`riser.stl` is left over from the earlier load-cell design and is no longer used — the
platform now bolts straight onto the pedestal.)

Print `platform` at 6 perimeters and 60 % infill so the cup sits on a flat, rigid disc.

## The stack, bottom to top

Heights are from the outside of the box's floor, so you can check them with a ruler:

```
   161  ── wet lid underside
   152.5── cup rim
   131  ── milk surface (175 mL)
    85.5── inside of the cup floor
    82.5── platform top          ← the cup stands here
    77.5── platform bottom       platform.stl, 5 thick
     3   ── pedestal base        printed into the floor, 74.5 tall
     0   ── bench
```

The pedestal is tall on purpose. The probes hang from the lid and only the pH probe is long
enough to reach far down, so the pedestal lifts the milk up to meet the short ones.

## Every fastener in the box

| Joint | Fastener | Notes |
|---|---|---|
| Platform → pedestal | 2 × **M4 × 25**, from **above**, down through the platform | Counterbored so the heads sit below the cup floor. 15 mm apart |
| TFT | 4 × M2 × 6 self-tapping | Into the bosses behind the window |
| TCS34725 | 2 × M2 × 6 self-tapping | Into the two bosses on the partition |
| Pump | 1 zip tie | Over the pump, through the two floor loops |
| Perfboard | **none** | Drops onto the rails; four snap tabs hold it |
| Dry lid | **none** | Four snaps |
| Wet lid | **none** | Drops into the opening |

Six screws and one zip tie for the whole instrument.

## Installing it

1. **Platform first.** Bolt the `platform` disc onto the top of the pedestal printed into the
   wet floor — two M4 from above, heads counterbored below the cup floor. Platform top lands
   at **z = 82.5**.

   That pedestal is deliberately tall. The probes hang from the lid, and only the pH probe is
   long enough to reach down a tall cup — a 50 mm DS18B20 cannot span from the lid to liquid
   sitting at the bottom of a 105 mm one. So the cup is short and the pedestal lifts the
   liquid up into probe reach instead.
2. **TCS34725** on the two M2 bosses on the wet face of the partition, at mid-liquid height,
   looking at the cup across a 4 mm air gap. No hood needed — the closed wet bay is its dark
   box. R, G, B and Clear are four of the model's features, so this one is not optional.
3. **Pump** on the dry bay floor, front-left. It lives *under* the board, with 7 mm of
   clearance over it.
4. **Perfboard** drops in from above onto the rails at z = 50 and is trapped by four corner
   clips. No screws, and no mounting holes needed in the board. Front and rear stops locate it.
5. **TFT** onto the four M2 bosses behind the front window. (There is no touch pad — the
   device is driven from the browser dashboard, so the old pad pocket is unused.)
6. **Ports**: panel micro-USB and the 12 V jack in the rear wall of the dry bay. The
   distilled-water line enters the rear wall too, runs to the pump, crosses the partition, is
   restrained by the boss on the wet bay's rear wall, and **plugs into the nozzle hole in the
   wet lid** at the 30° position.

   That outlet is in the lid, not the wall, and it had to be: the cup fills the bay to within
   8 mm of each side wall and its rim clears the lid by only 8.5 mm, so no wall position is
   actually over the cup — water from a wall nozzle lands on the floor. Leave a service loop
   long enough to set the lid down beside the box with the tube still attached, and tie it off
   at the wall boss so the loop never pulls on anything.
7. **Probes** into the wet lid: turbidity down the centre, pH / TDS / DS18B20 on the 27 mm
   bolt circle, one spare ⌀8 gland.

Keep the probes centred in the cup, not touching its wall, so each one reads the milk rather
than the acrylic. Clip the probe leads to the lid and to the box.

---

## Using it

1. Lift the wet lid off by its two rails — no fasteners. **Park it inverted across the open
   wet bay**: the rails land on the box's own left wall and partition, and the probes point
   safely up. Do not lay it on the bench — 80 mm of pH probe sticks up above the plate, so on
   a flat surface the lid balances on that one probe.
2. **Lift the cup out and fill it at the sink**, to the weir. Overfilling is the point — the
   weir sets a consistent fill line, so the probes are always submerged to the same depth.
   Fill it outside the box and the overflow goes down the drain instead of onto the bay floor.
3. Cup back in, lid on. Capture from the dashboard.
4. Lid off, cup out, dump the milk, cup back, lid on.
5. Flush from the dashboard. It pumps distilled water over the probes and into the cup.
6. Lid off, cup out, dump the water, cup back, lid on. Ready.

There is **no waste plumbing anywhere** — you dump the cup by hand, which is why one pump is
enough, and why the rinse actually cleans instead of diluting.

---

## Printing

| Part | Orientation |
|---|---|
| `body` | as rendered — 212 × 178 × 161 |
| `wet_lid` | flat, feet upward |
| `dry_lid` | flat |
| `platform` | flat, 6 perimeters, 60 % infill — a flat, rigid disc for the cup |

```bash
openscad -o body.stl -D 'part="body"' hardware/enclosure-simple.scad
```

Walls are **3.0 mm on the wet bay and 2.4 mm on the dry bay and lids**. The wet bay is
thicker because it holds a full cup of milk and gets rinsed; the dry side just covers
electronics. Outer faces stay flush — the dry bay is simply 1.2 mm roomier inside.

Not printed: the cup (acrylic tube **⌀70 ID / ⌀76 OD × 70 tall**, ⌀6 weir hole drilled 45.5 mm
above the inside of its floor), TCS34725, perfboard, pump, tube, fasteners.

---

## Before you print

- **Measure every probe's length, and read the reach check.** This is the most important check
  in the file. Each probe hangs from the lid and has to physically span down into the liquid;
  the script prints one line per probe, and all four currently pass:

  ```
  Reach pH:      needs 69.5 mm below the lid, probe is 150  OK
  Reach TDS:     needs 45.0 mm below the lid, probe is  60  OK
  Reach DS18B20: needs 45.0 mm below the lid, probe is  50  OK
  Turbidity gap: z=121 — liquid is 85.5..131.0  OK, 10.0 mm under the surface
  Turbidity tips: z=114 vs cup floor 85.5  OK
  ```

  Put your measured lengths into the `probes` list. If a line says SHORT, raise `ped_h` — it
  lifts the liquid toward the lid — but keep the cup rim under 155. Keep each probe centred in
  the cup rather than letting it hang on its cable against the wall, so it reads the milk.

- **The turbidity sensor hangs inverted, and that is deliberate.** Per its datasheet it is
  ⌀30 at the base, 34 tall, with two arms 22 mm across and a 5.7 mm optical gap between them,
  and it is designed to mount in a tank floor with those arms pointing *up*. It cannot be used
  that way here, so it drops into a printed collar under the lid, arms down in the milk,
  **pins up and dry**, positioned so the optical gap sits 10 mm below the surface. `turb_drop`
  is the adjustment.

  Its ⌀30 base is also what sets the minimum cup bore: `cup_id ≥ 30 + 2 × (12 + 1.2) = 56.4`.
  At ⌀70 there is plenty of margin, so the box is not bore-limited.
- **Confirm the perfboard.** Modelled at 152 × 102 with 5 mm clearance each side.
- **This build uses a 3.3 V relay** to switch the pump, driven straight from GPIO25 (see
  [`docs/wiring.md`](wiring.md)). It is active-HIGH, so `PUMP_ACTIVE_LOW` defaults to `false`
  in [`sensors.h`](../libs/AquaMilkSensors/src/sensors.h); flip it to `true` if your module
  is active-LOW. The enclosure doesn't care either way.

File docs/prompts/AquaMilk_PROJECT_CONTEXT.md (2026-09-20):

# Aqua Milk Detect — PROJECT CONTEXT (single source of truth)

> Every agent building any part of this project MUST read this file first and treat it as authoritative. If a prompt and this file disagree, this file wins. Keep the same names, pins, colors, and schema everywhere.

**Tagline:** *Milk purity in seconds.*
**One line:** A low-cost, portable IoT + edge-ML device that classifies a milk sample as **Pure / Water-adulterated / Detergent-adulterated / Starch-adulterated** (or **Uncertain**) in seconds, using multi-sensor data and an on-device SVM, with a self-cleaning flush and an elegant web + on-device UI.

SDGs: 3 (Good Health), 9 (Industry/Innovation), 12 (Responsible Consumption).

---

## 1. System overview (three stages, one repo)

The system is delivered as **three separate Arduino firmwares** plus **one web app**, **one Python trainer**, and **CI to build + host**:

| Stage | Folder | Runs on | Talks to browser via | Purpose |
|---|---|---|---|---|
| 1. Calibration & test | `01_calibration/` | ESP32 | **USB Web Serial** | Read + calibrate each sensor and all-at-once |
| 2. Data collection | `02_collection/` | ESP32 | **USB Web Serial** | Capture labelled samples → CSV in browser |
| 3. Deployment | `03_deployment/` | ESP32 | **Wi-Fi (SoftAP / STA)** + TFT | Run the trained SVM, show verdict, self-flush |
| Web app | `web/` | GitHub Pages | — | Flash firmware + Calibrate + Collect UIs |
| Trainer | `training/` | User PC (Python) | — | Train SVM from CSV → export `model.h` |
| CI | `.github/workflows/` | GitHub Actions | — | Build `.bin`s + deploy `web/` to Pages |

**Data/ML loop:** Stage 2 collects labelled CSV → Python trainer makes `model.h` → drop into Stage 3 → deploy.

---

## 2. Hardware (FINAL bill of materials)

**MCU:** ESP32 DevKit V1, 38-pin, ESP32-WROOM-32 (user owns). Framework: **Arduino (arduino-esp32 core)**. NOT ESP-IDF.

**Sensors & modules:**
| Function | Part | Interface | Notes |
|---|---|---|---|
| pH | Analog pH sensor kit (Industrial Grade Analog pH, BNC probe) | Analog → ADC1 | Detergent (alkaline) flag; output may reach ~3–5 V → **see ADC note** |
| TDS / conductivity | DFRobot Gravity Analog TDS (genuine) | Analog → ADC1 | Water/detergent dilution; library `GravityTDS` |
| Turbidity | Turbidity Sensor With Module | Analog → ADC1 | Starch/suspended solids; output 0–4.5 V → **needs divider** |
| Colour | TCS34725 RGB+Clear | I²C | R,G,B,Clear channels as features |
| Temperature | DS18B20 waterproof (genuine chip, 1 m) | OneWire | Temp compensation for pH/TDS/density |
| Density | HX711 + 3 kg load cell | HX711 2-wire | Weigh fixed-volume chamber → specific gravity |
| Display | 1.8" TFT ST7735, 128×160 | SPI | On-device verdict + status |
| Pump | 6 V peristaltic dosing pump | via relay | Auto-flush chamber with distilled water |
| Pump switch | **3.3 V relay module** (user owns) | GPIO (digital) | Driven direct from GPIO25 — see §4 |
| Flyback | 1N4007 diode (optional) | across pump | Cheap insurance against contact arcing |
| Power step-down | LM2596 buck | — | 12 V → 6 V (pump) and 5 V/3.3 V (logic) |
| Power source | 12 V 1.5 A adapter (user owns) | — | 18 W, ample |
| Input | **1 × TTP223 capacitive touch pad** (user owns) | GPIO (RTC pin) | Gesture-driven; **NO LEDs** |
| Fluidics | Silicone tube 1 m + user's reservoir & waste cup | — | Flush plumbing |

**User-owned / not purchased:** ESP32, 3.3 V relay module, 12 V 1.5 A adapter, 1N4007 diode (optional), TTP223 pad(s), jumper wires, breadboard.
**User to source separately:** enclosure + test chamber, distilled water, (optional, cheap) pH 4/7 buffer sachets.

**Purchase split (both free-shipping > ₹999, ₹0 shipping):**
- **Robu.in:** pH kit (₹1,975) + DS18B20 genuine-chip (₹89).
- **Robocraze:** DFRobot TDS, turbidity, 6 V pump, TCS34725, 1.8" TFT, 3 kg load cell + HX711, LM2596, silicone tube.
- Total to buy ≈ **₹4,969** (under ₹5,000 budget). Owned parts saved ≈ ₹600.

---

## 3. Pin map (ESP32-WROOM-32, 38-pin) — FINAL

Use these exact pins in all firmwares.

| Signal | GPIO | Notes |
|---|---|---|
| pH analog in | **36** (VP, ADC1_CH0) | input-only, ADC1 |
| TDS analog in | **39** (VN, ADC1_CH3) | input-only, ADC1 |
| Turbidity analog in | **34** (ADC1_CH6) | input-only, ADC1 |
| TCS34725 SDA | **21** | I²C |
| TCS34725 SCL | **22** | I²C |
| DS18B20 data | **4** | OneWire + 4.7 kΩ pull-up to 3V3 |
| HX711 DOUT | **16** | |
| HX711 SCK | **17** | |
| TFT SCLK | **18** | VSPI |
| TFT MOSI | **23** | VSPI |
| TFT CS | **5** | strapping pin — fine as output |
| TFT DC | **2** | strapping pin — fine as output |
| TFT RST | **15** | strapping pin — fine as output |
| TFT BL (backlight) | tie to 3V3 (or **32** for dim) | |
| Pump (relay IN) | **25** | Plain digital output (active-HIGH) |
| TTP223 OUT | **27** | RTC-capable → deep-sleep touch wake (ext0) |

**ADC rules (critical):**
- All three analog sensors are on **ADC1** because **ADC2 is unusable while Wi-Fi is on**.
- ESP32 ADC is 12-bit, 0–3.3 V. **Any sensor board that can output > 3.3 V (turbidity 0–4.5 V; pH board can approach 5 V) MUST go through a resistor voltage divider** (e.g. 2:1) or the board must be run at 3.3 V. Document the divider in the wiring README. Calibration maps raw ADC → sensor value, so exact divider ratio is captured during calibration.
- Use `analogReadMilliVolts()` / attenuation `ADC_11db` for the widest linear range; average many samples.

Free/unused pins for future use: 13, 14, 26, 33, 35 (35 input-only). Avoid GPIO12 (strapping, boot).

---

## 4. Power & pump switching (3.3 V relay)

Power: 12 V adapter → LM2596 #1 set to **6 V** for the pump; logic runs from **5 V/USB or a second LM2596 at 5 V**. ESP32 from 5 V pin or USB.

Pump switching uses a **3.3 V relay module** driven straight from the ESP32 — the module's onboard driver transistor and flyback do the work, so GPIO25 sources almost no current and no level-shifter is needed. Firmware therefore:
- Drives the pump as a **plain digital output on GPIO25** (`pinMode(OUTPUT)` + `digitalWrite`). **Never PWM a relay** — the coil would chatter. Pump control is on/off only.
- Uses a `PUMP_ACTIVE_LOW` compile-time flag for the module's polarity. **This build's module is active-HIGH (GPIO HIGH = pump ON), so the flag defaults to `false`.** For the common opto-isolated boards that energize on LOW, set it `true`.
- Wiring: `GPIO25 → relay IN`, `3V3 → relay VCC`, `GND → relay GND`, and the pump's +6 V feed through the relay `COM`/`NO` contacts. A **1N4007 across the pump** (band → +6 V) is optional insurance against contact arcing.

---

## 5. Data schema (CSV) — FINAL

One captured sample = one CSV row. Store **raw** sensor values (so features can be re-derived) plus labels & metadata.

```
timestamp_iso, milk_type, adulterant, level_pct, source,
temp_c, ph_raw_mv, tds_raw_mv, turbidity_raw_mv,
density_g, color_r, color_g, color_b, color_clear
```

- `milk_type` ∈ {cow, buffalo, toned}
- `adulterant` ∈ {pure, water, detergent, starch}
- `level_pct` ∈ {0, 5, 10, 20, 30, …} (0 for pure)
- `source` = free text (dairy / shop / person / place) — **user's tagging field**
- `*_raw_mv` = averaged ADC millivolts; `density_g` = temp-corrected grams for the fixed volume; color_* = TCS34725 channels.
- CSV is created and saved **in the browser** (no server, no SD card).

**Feature vector for the model (≈10):** `ph, tds, turbidity, density(temp-corrected specific gravity), temperature, color_r, color_g, color_b, color_clear` (+ optionally derived ratios). Fit a `StandardScaler`; export scaler constants alongside the model.

---

## 6. Model & inference

- **Algorithm:** SVM (scikit-learn). Compare **linear vs RBF** via `GridSearchCV` + stratified k-fold; pick best by macro-F1.
- **Classes:** `pure, water, detergent, starch`. Also compute a **binary headline** (pure vs adulterated).
- **Uncertain / reject:** use `predict_proba` (Platt) — if top-class probability `< threshold` (default **0.60**, tunable in the deployment Settings), output **Uncertain**. Optionally a one-class outlier guard on "pure".
- **Export:** `micromlgen` → `model.h` (C++), plus a `scaler.h` (means/scales) → included by `03_deployment`. Inference on-device is microseconds.
- **Honesty:** trainer must print accuracy, macro-F1, full **confusion matrix**, per-class precision/recall, and note that starch is the hardest class. Report both multiclass and binary numbers.

---

## 7. Interaction — single TTP223 gestures (deployment)

**No LEDs.** All feedback is on the **TFT** and the **web dashboard**. One touch pad, gesture vocabulary (keep timing generous; show a gesture cheat-sheet in the menu):

| Gesture | Action |
|---|---|
| **Single tap** | Start a test |
| **Double tap** | Flush now |
| **Long-press (~1.5 s)** | Open on-screen menu → navigate with taps (Wi-Fi info · Tare · Re-check calibration · Settings) |
| **Tap-tap-hold** | **Soft power**: enter deep sleep (screen/Wi-Fi off, µA). A touch **wakes** it (ext0 on GPIO27). No true hardware off (a touch pad can't power a dead board); a physical switch on the adapter gives hard-off if desired. |

Test flow: sample in → single tap → TFT shows "Reading…" (average ~3 s) → verdict + confidence → **auto-flush ~5 s** → ready. Uncertain → amber "Uncertain — retest", auto-suggest flush + retry.

---

## 8. Connectivity & protocol

- **USB Web Serial (Stages 1 & 2):** newline-delimited **JSON**. Baud 115200.
  - Device→browser: `{"t":"reading","ph":..,"tds":..,"turb":..,"temp":..,"dens":..,"r":..,"g":..,"b":..,"c":..,"ts":..}`
  - Browser→device: `{"cmd":"capture"}` · `{"cmd":"calibrate","sensor":"ph","point":7.0}` · `{"cmd":"tare"}` · `{"cmd":"flush","ms":5000}` · `{"cmd":"set","key":"..","val":..}`
  - Device acks: `{"t":"ack","cmd":"..","ok":true,"msg":".."}`
- **Wi-Fi (Stage 3):** default **SoftAP** SSID `AquaMilk-XXXX` (XXXX = last 2 bytes of MAC), password shown on TFT; device serves its own dashboard at `http://192.168.4.1` with a **WebSocket** for live data. Optional **STA** (join lab Wi-Fi, creds set in Settings) reachable at **`aquamilk.local`** via mDNS. HTTP only on-device (that's why Run is device-served — an HTTPS page can't call an HTTP device: mixed content).

---

## 9. Design language (Apple-grade) — shared by web app AND device dashboard

**Use the installed Apple design skill for all UI work.** Both the GitHub-hosted app and the ESP32-served Run page share this system.

- **Type:** `-apple-system, "SF Pro Text", "SF Pro Display", system-ui, sans-serif`. Big rounded titles, strong hierarchy, tight tracking on large text.
- **Theme:** **light + dark, auto (`prefers-color-scheme`), default light.**
- **Palette:**
  - Accent (aqua-teal): `#0FB5C9` (darker `#0A8FA3`)
  - Backgrounds: light `#F5F7FA`, dark `#0B0F14`
  - Cards/surfaces: light `#FFFFFF`, dark `#161B22`, with subtle translucency/blur (frosted) where tasteful
  - **Result semantics:** Pure = green `#34C759` · Adulterated = red `#FF3B30` · Uncertain = amber `#FF9F0A` (Apple system colors)
- **Shape & motion:** 16–20 px corner radius, soft layered shadows, 8-pt spacing grid, 200–300 ms ease transitions, gentle spring on the result reveal, circular **confidence ring** (SVG). SF-style segmented controls, toggles, large tap targets.
- **Tone:** calm, spacious, confident. No clutter, no debug vibes. Production-grade.
- **Branding:** title **"Aqua Milk Detect"**, tagline **"Milk purity in seconds"**, a **minimal logo mark** (agent designs it — think a clean drop/wave in aqua-teal). Provide as inline SVG.
- **Device dashboard constraint:** must be lean enough to live in ESP32 flash (single gzipped HTML/CSS/JS in PROGMEM or LittleFS) yet visually identical in spirit.

---

## 10. Repo layout (created by CI prompt)

```
aquamilk-detect/
├── PROJECT_CONTEXT.md          ← this file (source of truth)
├── README.md                   ← wiring, setup, usage, wiring diagram
├── 01_calibration/             ← Arduino sketch
├── 02_collection/              ← Arduino sketch
├── 03_deployment/              ← Arduino sketch (+ model.h, scaler.h, web assets)
├── web/                        ← the GitHub-Pages SPA (Flash/Calibrate/Collect/Run)
│   └── firmware/               ← .bin + ESP Web Tools manifests (built by CI)
├── training/                   ← Python trainer (notebook + script) → model.h
├── docs/                       ← diagrams, images
└── .github/workflows/          ← build + deploy
```

## 11. Global conventions
- License **MIT**. Author: Nikhil.
- Each sample/test **averages ~3 s** of readings. Auto-flush default **5 s** (adjustable in Settings).
- Confidence threshold default **0.60** (Settings).
- Store calibration constants + settings + rolling log in **NVS (`Preferences`)**; larger logs/assets in **LittleFS**.
- Persistent rolling test log kept on device flash (last ~200 results), plus full session history in the browser (exportable CSV).
- Prompts assume a capable coding agent (files + shell + arduino-cli/PlatformIO + Git/GitHub + skills). Target boards/libs pinned by CI.
- Web Serial + ESP Web Tools work in **desktop Chrome/Edge only** (state this in the app UI).

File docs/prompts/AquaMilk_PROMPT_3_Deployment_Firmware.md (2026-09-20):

# AGENT PROMPT 3 — Deployment Firmware (`03_deployment/`)

**Read `PROJECT_CONTEXT.md` first (pin map §3, power/pump §4, model §6, gestures §7, connectivity §8, design §9, conventions §11). Reuse `sensors.h/.cpp`. Use the installed Apple design skill for the device-served dashboard.**

## Your task
Write an **Arduino (ESP32)** sketch `03_deployment.ino` — the finished, standalone tester. It runs the trained SVM on-device, shows the verdict on the TFT, serves its own elegant Wi-Fi dashboard, self-flushes, is driven by one touch pad, and supports soft-power sleep.

## Core flow
1. **Boot:** init sensors, load calibration + settings from NVS, mount LittleFS, include `model.h` + `scaler.h` (from the trainer). Start Wi-Fi in **SoftAP** by default (`AquaMilk-XXXX`, §8); if STA creds saved, join and advertise `aquamilk.local` (mDNS). Serve the dashboard (below) + a **WebSocket** for live push. Show idle screen on TFT (logo, "Tap to test", Wi-Fi/SSID).
2. **Test (single tap or dashboard button):** TFT + dashboard show "Reading…"; take a **~3 s averaged** feature reading; apply calibration + `StandardScaler` (from `scaler.h`); run SVM (`model.h` via micromlgen) → class probabilities.
   - If top prob ≥ threshold (default 0.60, from Settings) → verdict = that class; else **Uncertain**.
   - Show verdict big on TFT with the semantic color (§9): green Pure / red Adulterated-type / amber Uncertain, plus confidence and a one-line reason (top contributing sensors). Push the same to the dashboard over WebSocket.
   - Also compute + show the **binary headline** (Pure vs Adulterated).
   - **Auto-flush** (~5 s, per §4) then return to idle. Log the result.
3. **Uncertain:** amber "Uncertain — retest", auto-suggest flush + retry.

## Touch gestures (§7) — implement robust detection on GPIO27 (single TTP223)
- **Single tap** → start test. **Double tap** → flush now. **Long-press ~1.5 s** → open on-screen menu (navigate with taps: Wi-Fi info · Tare · Re-check calibration · Settings; show a gesture cheat-sheet here). **Tap-tap-hold** → **soft power**: display "Sleeping…", then `esp_deep_sleep_start()`; configure **ext0 wake on GPIO27** so a touch wakes it. Keep timing windows generous and debounced.

## Wi-Fi dashboard (device-served, Apple-grade, LEAN)
Serve a single self-contained page (HTML+CSS+JS, **gzipped in PROGMEM or LittleFS**) that mirrors the web app's design language (§9) but lightweight:
- **Verdict card:** big class word, **circular confidence ring** (SVG), semantic color, binary headline, timestamp.
- **Details (expandable):** every live sensor value + which features drove the decision (bar/relative contribution).
- **History:** this-session list (timestamped) **and** the persistent rolling log (last ~200) read from flash; export-to-CSV button (client-side).
- **Settings:** confidence threshold slider, flush duration, Wi-Fi mode (SoftAP/STA + creds), tare, re-check calibration, factory reset.
- **Controls:** "Run test" and "Flush" buttons (mirror the touch pad).
- Live updates via **WebSocket**; graceful reconnect. Works on any phone/laptop browser (it's plain HTTP on the device).

## Persistence & logging
- Settings + calibration in NVS (`Preferences`). **Persistent rolling test log** (last ~200 results: ts, class, confidence, key features) in LittleFS or NVS blob, survives power cycles (§11).

## Requirements / quality bar
- Respect `PUMP_ACTIVE_LOW` (§4) for all pump control; plain digital output on GPIO25 (3.3 V relay, active-HIGH — never PWM a relay).
- All analog on ADC1 (Wi-Fi safe, §3). Non-blocking main loop; async web server (`ESPAsyncWebServer` + `AsyncWebSocket`) recommended.
- `model.h`/`scaler.h` are **generated by the trainer** — commit placeholder stubs with a clear `// TODO: replace with trained model` and a matching feature-order contract so the sketch compiles before training.
- Feature order MUST match the trainer exactly: `[ph, tds, turbidity, density, temperature, color_r, color_g, color_b, color_clear]`. Document this contract in a shared `features.h`.
- Header comment: gestures, endpoints, WebSocket messages, feature order.

## Deliverables
`03_deployment/03_deployment.ino` (+ reused `sensors.h/.cpp`, `features.h`, placeholder `model.h`/`scaler.h`, gzipped `dashboard.html` asset + build note), and `03_deployment/README.md` (flash, first-run Wi-Fi, gestures, how to drop in the trained model). Verify it compiles under arduino-cli for `esp32:esp32:esp32` with the placeholder model.

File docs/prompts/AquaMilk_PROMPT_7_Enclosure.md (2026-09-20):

# AGENT PROMPT 7 — Enclosure (3D-printed) for Aqua Milk Detect

**Read `PROJECT_CONTEXT.md` first** (hardware §2, pin map §3, design language §9). This brief adds everything mechanical. **Act as a professional product + mechanical design engineer** — Apple-grade industrial design, but manufacturable on a home FDM printer with no screws. Do not cut corners; **do not miss anything below**; and **run the Self-Review checklist (§13) and fix all issues before you ship.**

---

## 0. Deliverable format
Produce a **parametric model in CadQuery (Python)** — preferred, because you can run it, parameterise every dimension, and export automatically. (OpenSCAD acceptable if you justify it.) Output:
- One parametric source file per part + a shared `params.py` (all key dimensions/tolerances as named variables).
- **Print-ready `STL` per part** and a `STEP` of the full assembly.
- An **exploded-view render (PNG)** and an assembled render.
- `ASSEMBLY.md` (snap order, magnet placement, cable routing) and `PRINT.md` (orientation, supports, bed mapping, material).
- A **printed-parts BOM** and a **hardware BOM** (magnets, tubing, drop-in cup, drop-in bottle, heat-shrink).
Everything must be regenerable by running the code.

---

## 1. What the device is (so the mechanics make sense)
A benchtop milk-purity tester. A user pulls out a **drawer**, drops milk into a **removable cup** up to an **etched fill line**, pushes the drawer in, and taps to weigh. A **bayonet sensor head** above the well is then **pushed and rotated 90°** so all probes plunge into the milk; a second tap reads the sensors; the ESP32 classifies. After the test the user raises the head, pulls the drawer, empties the cup, reinserts it, and a single pump squirts distilled water to rinse the probe tips. See PROJECT_CONTEXT §7/§8 for the electronics.

---

## 2. Industrial design language
- **Form:** low rectangular lab-instrument block, calm and seamless. Gentle **2–3 mm fillets** on all outer vertical edges; crisp but not sharp.
- **Colour:** **space-grey body** with **dark-blue accents** (NOT aqua). **Accents live ONLY on the top-most surfaces/top layer** (the angled front bezel edge + the recessed logo) so a single-extruder printer does at most **one filament swap near the end** — or deliver it **single-colour** (space-grey only) as an equally acceptable option. Never require mid-print swaps on internal layers.
- **Surface finish:** apply a **fine matte micro-texture** to all show surfaces (e.g. a subtle fuzzy/stipple or a shallow horizontal brush grain modeled into the faces, or specify a print texture) so it reads as a finished product, not a raw print. Chamfer/round every visible edge. **Recessed, debossed logo + "Aqua Milk Detect" wordmark + tagline "Milk purity in seconds"** on the top.
- **No transparent parts anywhere.** The TFT's own glass is the only "window" (it sits flush in a cutout). No added clear covers.
- **No screws anywhere.** Assembly is **snap-fit cantilever clips + alignment keys/dovetails**, with **embedded magnets** only on the two frequently-opened parts (rear reservoir door, cup lid if used).
- Hidden seams; all fasteners/joints concealed. **No visible wires** — everything routes in internal channels.

---

## 3. Overall envelope & the hard constraints
- **Printer bed: 250 × 250 × 250 mm.** Every single part must fit within that. Split the shell into snap-together modules accordingly.
- **Perfboard to house: 150 × 89 mm** (the 9×15 cm board), ~1.6 mm thick, with modules standing up to ~18 mm tall on top and connectors on its front edge. Provide a bay with **≥4 mm clearance around the board**, standoff bosses, and cable room above.
- **pH probe: 16 cm of rigid body** ending in the glass bulb — this sets the vertical stack. Head-up must clear the cup; head-down must submerge the bulb. Budget ~**180–200 mm** of vertical travel space for the probe + plunge + cup.
- **Target overall size (you refine):** roughly **W 150 × D 210 × H 240 mm**, staying ≤ 250 mm in every axis. If any part would exceed 250 mm, split it with a hidden snap joint.

---

## 4. Part breakdown (all snap-fit, each ≤ 250 mm)
Design at least these modules; add alignment keys so they self-locate:
- **A. Base chassis / tub** — feet, houses the electronics bay + rear utility bay; drawer rails.
- **B. Electronics bay** (inside A) — perfboard cradle + vents.
- **C. Rear utility bay** — removable distilled-water reservoir + pump mount, magnet door.
- **D. Drawer** — carries the removable cup, the load cell + HX711 satellite; slides on rails; hard-seat detent; interlock catch.
- **E. Removable cup + cradle** — the milk vessel + its locating cradle on the load cell.
- **F. Sensor-head assembly** — bayonet collar + head carriage holding all probes + flush nozzle + cable service loop + interlock tab.
- **G. Angled front bezel** — flush TFT cutout + hidden touch pad + logo (accent colour lives here).
- **H. Top lid** — closes the top, carries the head tower/bayonet mount and the pour access.

---

## 5. Drawer + cup + weighing (sub-assembly D & E)
- **Removable cup:** for hygiene and leak-safety, **do NOT rely on a bare FDM print as the milk-contact surface** (porous, hard to clean). Design the cup as a **printed cradle that holds a drop-in food-safe vessel** (a small ~60 ml stainless/glass shot-style cup) OR a printed cup **with a smooth food-safe interior** — recommend the drop-in insert and list it in the hardware BOM. Target usable volume **50–60 ml**; model a crisp **etched/embossed fill line** at ~50 ml.
- **One dedicated cup** — fixed tare & volume (firmware calibrates it once). The cradle must locate it repeatably (keyed seat) so it lands in the same spot every time.
- **Load cell** sits **in the drawer under the cup cradle**, on a rigid mount, with the cradle as its floating platform — **mechanically isolated** so only the cup's weight loads it (nothing else touches the platform). **HX711 mounts right next to the load cell in the drawer** (satellite); route only its 4 digital wires back to the board through a **strain-relieved service loop** that flexes with drawer travel (§9).
- **Drawer slide:** printed rails with a **hard stop + detent** at the fully-in position (so the platform is stable for weighing — no wobble). Smooth pull; add a finger recess (no visible handle hardware).
- **Interlock:** when the head is locked down (§6), a **tab physically blocks the drawer from sliding out**. Raising the head releases it. Model both the tab on the head and the catch slot on the drawer/chassis.

---

## 6. Bayonet sensor head (sub-assembly F) — the critical part
Carries, on one head, **all five probes + the flush nozzle**, and must place every tip correctly in the milk:
- **Probes on the head:** pH electrode (Ø~12 mm × 16 cm rigid, held near its top so the bulb hangs down), TDS probe, turbidity sensor, DS18B20 tip, **TCS34725 (potted/conformal-coated, aimed at the milk body just below the fill line)**, plus the **flush nozzle** (tube from the pump) aimed at the probe tips.
- **Immersion geometry (get this exactly right):** when the head is **locked DOWN** and the cup is filled to the line, **every tip sits ~12–18 mm below the milk surface** — pH bulb fully submerged, TDS electrodes submerged, turbidity window submerged, DS18B20 tip submerged, colour sensor just below the surface facing the milk. Parameterise each probe's Z-offset in `params.py`. Add a **hard depth-stop** so the fragile **pH glass bulb never touches the cup bottom** (leave ≥ 5 mm clearance to the bottom).
- **Bayonet action:** **push down + rotate 90° to lock** at the **correct final orientation** (probes arranged to clear each other and the cup wall); rotate back 90° + lift to raise. The locked angle is the "correct/straight" position — design the slot so it can only lock at that one angle. Include a light detent so it stays down hands-free during the test, and enough clearance that raising it is smooth.
- **Alignment:** the drawer's cup must land **precisely under the head** (keyed seat + drawer hard-stop) so the plunging probes never hit the cup wall.
- **Cable service loop:** all head cables (pH 80 cm, TDS 80 cm, temp 95 cm, turbidity sensor lead, colour) are **bundled in heat-shrink** and routed as a **service loop/light spiral anchored above the head** that absorbs the vertical plunge **and** the 90° twist without fatigue. Provide an anchor boss + a strain relief; leave generous slack.
- **Splash:** keep the bayonet mechanism and cable exit **above** the wet zone; add a small drip lip so rinse water can't wick up into the head.

---

## 7. Fluidics (single pump, no valves, no waste bottle)
- **One 6 V peristaltic pump** in the rear bay. Its only job: pull distilled water from the **internal reservoir** and push it through the head's **flush nozzle** to rinse the probe tips (head down, empty cup). The user empties the cup by hand — **there is NO waste bottle and NO valve**.
- **Reservoir:** a **removable ~500 ml distilled-water container** in the rear bay behind a **magnet door**; friction-fit / quick-pull tube to the pump. Recommend a **drop-in bottle** in a printed cradle (leak-free) rather than a printed tank. Pickup tube reaches the bottom.
- Route the pump→nozzle tube internally; model tube clips/channels so nothing dangles.

---

## 8. Electronics bay (sub-assembly B) + front bezel (G)
- **Perfboard cradle:** snap-in standoffs for the 150 × 89 mm board, oriented so its **front connector edge faces the cable channels**; ≥4 mm clearance all around; ≥15 mm headroom above for tall modules. Access to the ESP32's USB port from outside via a **hidden/edge slot** (for flashing/serial) — recessed, no flap needed.
- **Cable channels & clips** from the head loom and the drawer loom to the board's front edge — fully concealed, strain-relieved, no crossing over the board.
- **Angled front bezel (~18–22° tilt):** **TFT flush** in a precise cutout (its own glass is the surface — model to the TFT's exact bezel so the glass sits flush, no added cover). The **single TTP223 pad mounts BEHIND the opaque bezel** just below the display — no cutout (capacitive reads through ~2 mm plastic); mark its location with a **subtle debossed ring**. Recess for the TFT PCB behind. Accent (dark-blue) colour lives on this bezel's top edge + the logo.

---

## 9. Cable management (nothing visible)
- **Head loom:** heat-shrink bundle + service loop (see §6).
- **Drawer loom:** the HX711's 4 digital wires in a **flat service loop** that flexes with drawer travel; strain-relieved at both ends.
- Internal **channels, clips and pass-throughs** for every wire so the exterior is clean. Provide grommeted or filleted pass-throughs (no sharp edges on wire paths).

---

## 10. Thermal / vents
- Provide **convection venting** for the LM2596, the pump, and the ESP32: **low intake vents** near the base + **high exhaust vents** near the top-rear, positioned for natural airflow across the power corner. Style them as **tasteful fine louvre slits** (≤ 2 mm) that read as design, not holes — keep them on less-visible faces (rear/underside) where possible. Ensure vent slits are printable without supports (bridging-friendly orientation).

---

## 11. Tolerances & materials (state these in `params.py`)
- **Sliding fits** (drawer rails, bayonet): **0.30–0.40 mm** clearance per side. Not tight, not sloppy — smooth glide with a light detent.
- **Snap-fit clips:** cantilever arms ~6–8 mm long, ~1.5–2 mm thick at root, **~0.3 mm** engagement; design for repeated open/close on the doors.
- **Press/friction fits** (standoffs, tube ports): **0.10–0.15 mm** interference.
- **Magnet pockets:** pocket = magnet Ø **+0.15 mm**, depth = magnet + 0.4 mm (press or glue); pair polarity noted.
- **Walls:** **2.5–3 mm** typical; **3 mm** on any water/milk-adjacent or structural part.
- **Material:** recommend **PETG** for the shell and all wet/warm parts (moisture + mild heat from the pump/regulator; better layer adhesion than PLA). PLA acceptable for the outer shell only. **Milk-contact = the drop-in food-safe cup, not raw print.** Note all of this in `PRINT.md`.
- Design all overhangs **> 45°** or add chamfers so most parts print **support-free**; call out any part that needs supports.

---

## 12. Print strategy (`PRINT.md`)
- Map **each part to a print orientation** that minimises supports and puts layer lines across (not along) load paths, especially the snap clips and the bayonet.
- Confirm **every part ≤ 250 mm** in all axes; if not, split with a hidden snap joint + alignment key.
- Note the **single accent swap** (dark-blue, top layers only) or the single-colour option.
- Suggested settings: 0.2 mm layer, 3+ walls, 20–30% infill (higher at clips/rails), PETG temps.

---

## 13. SELF-REVIEW — run before you ship (mandatory)
Do NOT deliver until every item passes; fix and re-check:
1. **Fit checks in CAD:** no interference between any parts in the assembled STEP; drawer slides fully; bayonet rotates and locks; head raises and lowers freely.
2. **Probe immersion:** with the cup filled to the line and head locked down, verify (in the model, with the parameterised Z-offsets) that **all five tips sit 12–18 mm below the surface** and the **pH bulb clears the cup bottom by ≥ 5 mm**.
3. **Interlock:** confirm the drawer is physically blocked when the head is down and free when up.
4. **Perfboard fit:** the 150 × 89 mm board + tall modules + connectors fit the bay with the stated clearances; USB reachable.
5. **Bed fit:** every STL ≤ 250 mm in X, Y, Z.
6. **No-screws / no-transparent / accent-top-only:** confirm assembly uses only snaps + magnets, no clear parts, and the accent colour appears only on top-layer surfaces.
7. **Tolerances:** slides 0.3–0.4 mm, snaps ~0.3 mm, presses ~0.1–0.15 mm — sane and consistent.
8. **Cable paths:** head loom takes plunge + 90° twist; drawer loom flexes; nothing visible outside; nothing pinched.
9. **Vents:** intake-low / exhaust-high present over the power corner; printable.
10. **Wall thickness / watertightness / support-free** checks pass.
Write a short **`REVIEW.md`** listing each check and its result.

---

## 14. Deliverables recap
Parametric source (+`params.py`), per-part **STLs**, assembly **STEP**, exploded + assembled **renders**, `ASSEMBLY.md`, `PRINT.md`, `REVIEW.md`, printed-parts BOM, hardware BOM (magnets, tubing, drop-in food-safe cup, drop-in reservoir bottle, heat-shrink). Everything regenerable by running the code. Match the design language in PROJECT_CONTEXT §9 (with the enclosure accent overridden to **dark blue, top-layer only**).

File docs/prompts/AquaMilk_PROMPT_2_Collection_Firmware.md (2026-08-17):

# AGENT PROMPT 2 — Data Collection Firmware (`02_collection/`)

**Read `PROJECT_CONTEXT.md` first (pin map §3, schema §5, protocol §8, conventions §11). Reuse `sensors.h/.cpp` from `01_calibration/` verbatim — do not re-implement sensor code.**

## Your task
Write an **Arduino (ESP32)** sketch `02_collection.ino` that captures **labelled training samples** and streams them to the web app over **USB Web Serial**, where the browser writes the CSV. No Wi-Fi, no SD card.

## Behaviour
1. **Boot:** init sensors via shared module, load calibration from NVS, show "Collection mode" + sample counter on the TFT.
2. **Live stream** `{"t":"reading",...}` at ~5 Hz so the UI shows live values while the user prepares a sample.
3. **On `{"cmd":"capture"}`** (labels are attached by the browser, not the device):
   - Show "Capturing…" on TFT. Take a **~3 s averaged reading** (per §11): collect all sensor channels continuously, then report a single consolidated record `{"t":"sample","temp_c":..,"ph_raw_mv":..,"tds_raw_mv":..,"turbidity_raw_mv":..,"density_g":..,"color_r":..,"color_g":..,"color_b":..,"color_clear":..,"n":<reads averaged>,"ts":<ms>}`.
   - Then **auto-flush** (pump per §4, default 5 s) and report `{"t":"flush_done"}`. Increment + show the on-device counter.
   - The browser is responsible for prepending the labels (`milk_type, adulterant, level_pct, source`) and `timestamp_iso`, and appending the row to the in-memory CSV (per schema §5).
4. **Commands:** `{"cmd":"flush","ms":..}`, `{"cmd":"tare"}`, `{"cmd":"set","key":"avg_ms","val":3000}`, `{"cmd":"set","key":"flush_ms","val":5000}`, `{"cmd":"reset_counter"}`.
5. **Capture policy:** one `capture` = one averaged row (per user's decision). Do NOT auto-batch. Guard against captures while a flush is in progress (return `{"t":"ack","ok":false,"msg":"busy"}`).

## Requirements / quality bar
- Report **raw** values exactly as schema §5 names them so the CSV columns line up 1:1.
- Averaging must discard obvious outliers (e.g. trim top/bottom 10%) before mean; report the sample std-dev per channel too (`*_sd`) — useful for spotting a bad reading. (Extra fields are fine; the browser maps the known columns.)
- Non-blocking; robust JSON (ArduinoJson); ignore malformed input.
- Same TFT library + pins as `01_calibration`.
- Header comment lists commands + the exact `sample` field names.

## Deliverables
`02_collection/02_collection.ino` (reusing `sensors.h/.cpp`), and `02_collection/README.md` (how to flash, the capture workflow, field list). Verify it compiles under arduino-cli for `esp32:esp32:esp32`.

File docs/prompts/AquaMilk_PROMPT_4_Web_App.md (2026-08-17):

# AGENT PROMPT 4 — Web App (`web/`, GitHub Pages)

**Read `PROJECT_CONTEXT.md` first (design §9, protocol §8, schema §5, conventions §11). USE THE INSTALLED APPLE DESIGN SKILL for the entire UI — this is the showpiece; it must look genuinely Apple-grade. Also use any other fitting skills.**

## Your task
Build a single, elegant **static single-page web app** (no backend) hosted on GitHub Pages that does three jobs over **USB Web Serial** + one launcher. It must be beautiful, calm, production-grade — not a dev tool.

## Tech
- Plain HTML/CSS/JS or a light framework (React+Vite or Svelte are fine) that builds to **static files** in `web/dist` (or `web/`). No server. Must work as static hosting.
- Use the **Web Serial API** (`navigator.serial`) for Calibrate/Collect, and **ESP Web Tools** (`esp-web-tools` `<esp-web-install-button>`) for Flash. Both require **desktop Chrome/Edge + HTTPS** — detect and show a friendly notice if unsupported (and on mobile).
- Implement the JSON line protocol from §8 (a small `serial.js` that connects, reads newline JSON, writes commands, auto-reconnects).
- **No localStorage for critical data**; keep session state in memory. (CSV is downloaded, not stored.)

## Structure — one app, top nav: **Home · Flash · Calibrate · Collect · Run**
1. **Home:** hero with the **minimal aqua-teal logo mark**, title "Aqua Milk Detect", tagline "Milk purity in seconds", a one-line what-it-does, and four large cards linking to the sections. Show a subtle "Desktop Chrome/Edge required for Flash/Calibrate/Collect" hint.
2. **Flash:** three tidy cards — Calibration / Collection / Deployment firmware — each with an ESP Web Tools install button pointing at its manifest in `web/firmware/<name>-manifest.json`. Show connect state + progress. Brief "how to enter bootloader if needed" note.
3. **Calibrate:** a "Connect device" button (Web Serial) → then a clean panel per sensor showing **live values** with big readouts, plus calibration actions: pH (capture pH 7, capture pH 4, or a "use raw / skip" toggle), TDS (calibrate/keep default), Turbidity (set clear-water zero), Colour (set white reference), Density (Tare, then "set span with known weight" input), and a **"Test all sensors"** live grid to sanity-check wiring. Reflect stored constants returned by the device. A "Flush test" button.
4. **Collect:** "Connect device" → a **label form** (milk type ∈ cow/buffalo/toned · adulterant ∈ pure/water/detergent/starch · level % · **source** free-text) using SF-style segmented controls + inputs. A big **Capture** button that sends `{"cmd":"capture"}`, waits for the device's `sample`, prepends the labels + ISO timestamp, appends a row to an in-memory table (schema §5), shows a **live samples table**, **per-class counts** (so the user sees when the dataset is balanced), and **Export CSV** (client-side download). Live sensor values shown while preparing. Guard the button during flush.
5. **Run:** a launcher card explaining the finished tester is standalone: "Power the device, join its **AquaMilk-XXXX** Wi-Fi (password on the screen), open **http://192.168.4.1**" with a copy-link button and a note about optional `aquamilk.local`. Explain (kindly) why Run isn't embedded here (device is HTTP; this page is HTTPS → browsers block mixed content), so the dashboard lives on the device.

## Design requirements (Apple)
- Follow design §9 exactly: system fonts, **light+dark auto (default light)**, aqua-teal `#0FB5C9` accent, result colors green/red/amber, 16–20 px radii, soft shadows, frosted surfaces where tasteful, 8-pt grid, 200–300 ms transitions, gentle spring on state changes, large tap targets, generous whitespace. Circular confidence ring component available for reuse by the device dashboard.
- Fully responsive; keyboard accessible; reduced-motion respected.
- Provide the logo mark as inline SVG and reuse it on the device dashboard for consistency.

## Deliverables
Everything under `web/` building to static output, a shared `serial.js`, a `design/tokens.css` (the shared design variables also used by the device dashboard), the logo SVG, and `web/README.md`. Placeholder manifests + a note that CI fills `web/firmware/` with real `.bin`s. Ensure it runs when served over HTTPS (GitHub Pages).

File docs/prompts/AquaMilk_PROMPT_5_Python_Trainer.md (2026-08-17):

# AGENT PROMPT 5 — Python SVM Trainer (`training/`)

**Read `PROJECT_CONTEXT.md` first (schema §5, model §6, feature order in Prompt 3 / `features.h`, conventions §11).**

## Your task
Write a **Python** pipeline that turns the collected CSV(s) into a trained SVM and **exports `model.h` + `scaler.h`** for the deployment firmware, with an honest evaluation. Deliver both a **script** (`train.py`) and a **Jupyter notebook** (`train.ipynb`) that share a `utils.py`.

## Data
- Input: one or more CSVs matching schema §5 (columns: `timestamp_iso, milk_type, adulterant, level_pct, source, temp_c, ph_raw_mv, tds_raw_mv, turbidity_raw_mv, density_g, color_r, color_g, color_b, color_clear`). Support globbing a `data/` folder and concatenating.
- **Label = `adulterant`** (4 classes: pure, water, detergent, starch).
- **Features (exact order, must match `features.h`):** `[ph, tds, turbidity, density, temperature, color_r, color_g, color_b, color_clear]`.
  - Map raw → feature: apply the same calibration the firmware uses where relevant, OR train on raw values but document it; **temperature-correct the density** (specific gravity referenced to a standard temp) and keep `temperature` as its own feature.
  - Provide a single, documented `raw_to_features(df)` so firmware and trainer agree.

## Pipeline
1. Load + concat + clean (drop NaNs, obvious sensor faults). Print class counts and **warn on imbalance** across `adulterant` AND across `milk_type`/`source` (so the user knows if the model may overfit a source).
2. `StandardScaler` on features (save means/scales).
3. **Model selection:** `GridSearchCV` over SVM **linear vs RBF**, `C`, `gamma`, with **stratified k-fold (k=5)**; scoring **macro-F1**; `probability=True` (for the uncertain threshold).
4. **Honest evaluation** (print + save to `training/report/`): accuracy, macro-F1, per-class precision/recall/F1, **full confusion matrix** (also as a PNG), and a **binary pure-vs-adulterated** summary. Explicitly note starch is typically the hardest class. Show a held-out test split result, not just CV.
5. **Uncertain threshold analysis:** sweep the probability threshold (0.4–0.9), plot accuracy vs coverage, recommend a default (~0.60) and print how many test samples fall to "Uncertain" at that level.
6. Optional: quick **feature-importance** view (permutation importance) so the user can see which sensors matter.
7. **Export:**
   - `model.h` via **`micromlgen.port(clf)`** (SVM → C++), namespaced so it drops into `03_deployment`.
   - `scaler.h`: `const float FEAT_MEAN[9] = {...}; const float FEAT_SCALE[9] = {...};` in the exact feature order, plus the chosen `CONF_THRESHOLD` default.
   - Print a one-line "copy these two files into `03_deployment/`" instruction.
8. Save the fitted pipeline (`joblib`) and a `metrics.json`.

## Quality bar
- Deterministic (`random_state`), reproducible; `requirements.txt` pinned (`scikit-learn, pandas, numpy, matplotlib, micromlgen, joblib`).
- Do NOT overstate results — the report must be usable in the user's viva/thesis as an honest evaluation. Include a short "limitations" note (dataset size, source diversity, drift).
- Guard against tiny datasets (clear message if too few samples per class).

## Deliverables
`training/train.py`, `training/train.ipynb`, `training/utils.py`, `training/requirements.txt`, `training/data/.gitkeep`, `training/report/` (populated on run), and `training/README.md` (how to run, where CSVs go, how to move `model.h`/`scaler.h` into `03_deployment`). Include 2–3 rows of **synthetic sample data** so the pipeline runs end-to-end before real data exists (clearly marked synthetic).

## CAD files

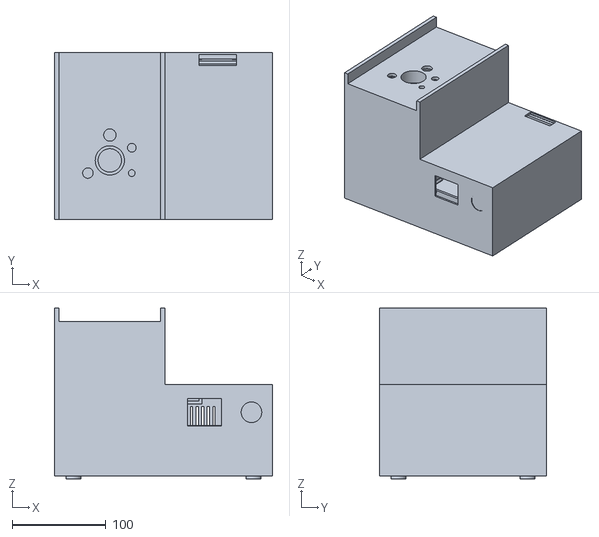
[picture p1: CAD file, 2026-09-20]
hardware/enclosure-simple.stl
232.4 x 178.0 x 182.0

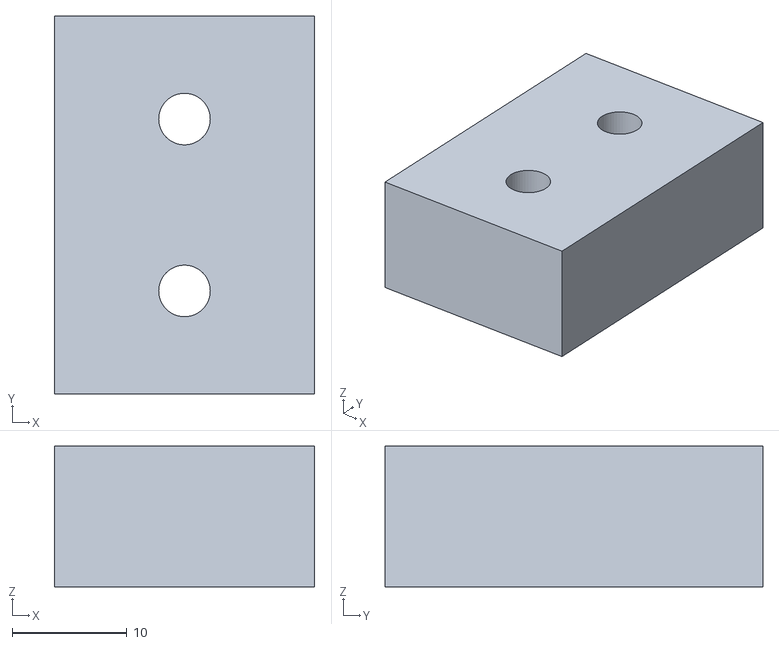
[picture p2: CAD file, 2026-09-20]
hardware/stl/riser.stl
22.7 x 33.0 x 12.3

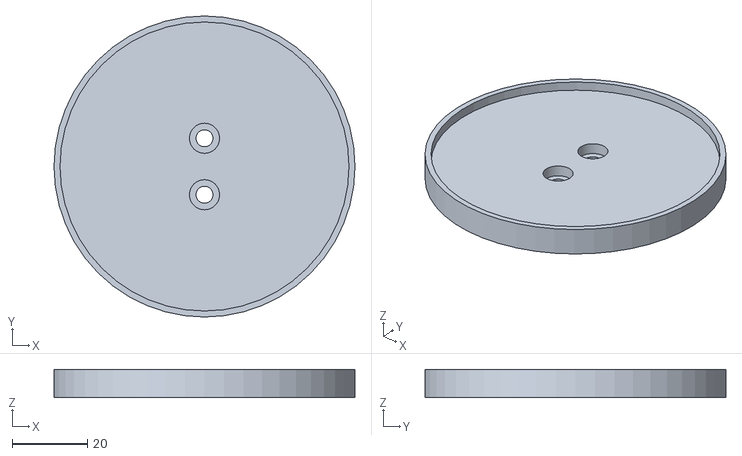
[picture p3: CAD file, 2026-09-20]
hardware/stl/platform.stl
80.0 x 80.0 x 7.50

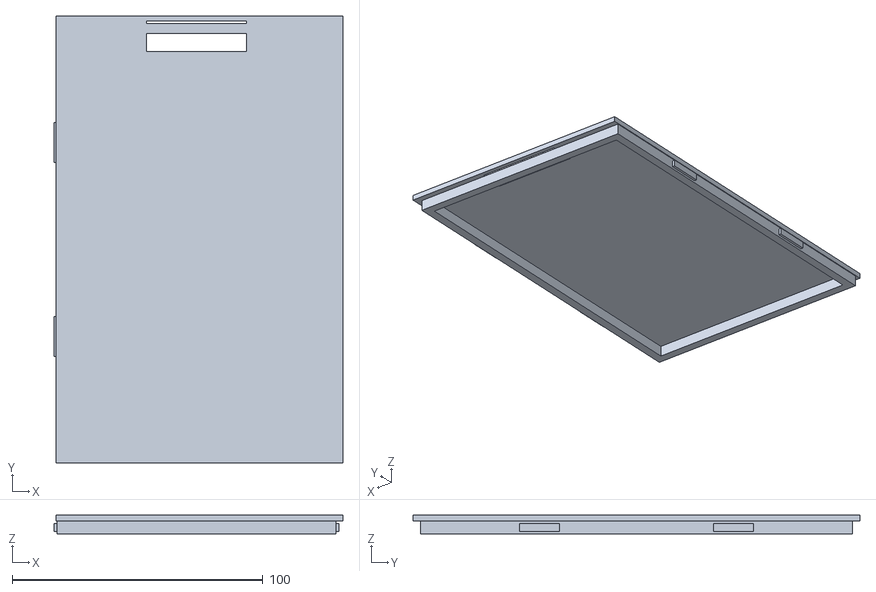
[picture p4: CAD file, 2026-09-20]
hardware/stl/dry_lid.stl
115.2 x 178.0 x 7.40

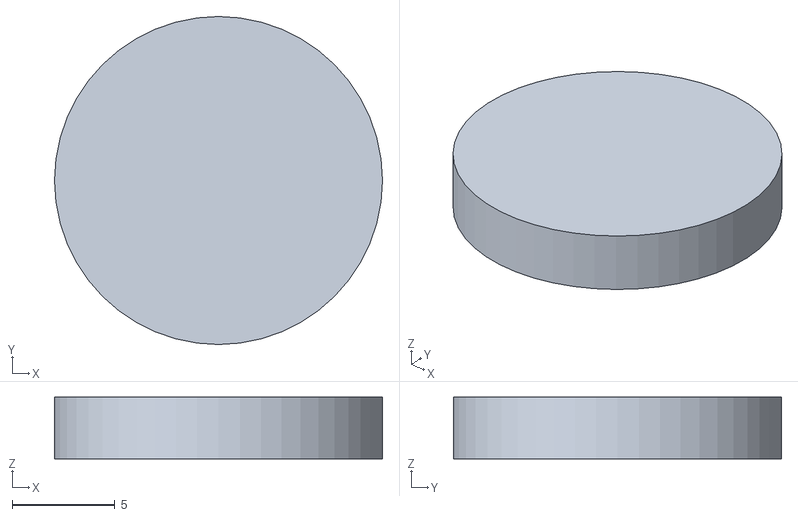
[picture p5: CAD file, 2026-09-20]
hardware/stl/foot.stl
16.0 x 16.0 x 3.00

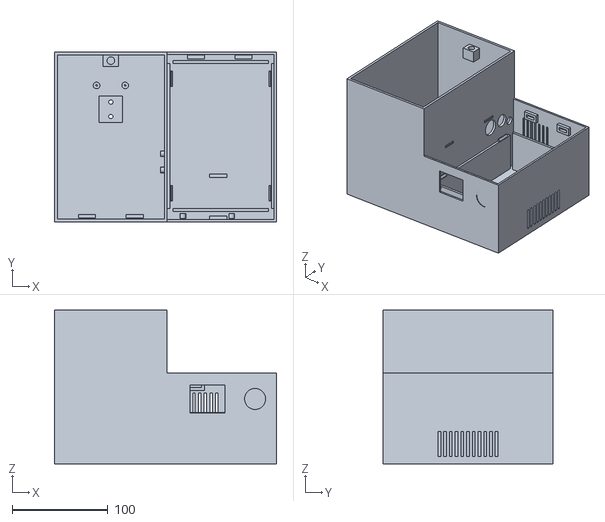
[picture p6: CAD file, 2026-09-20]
hardware/stl/body.stl
232.4 x 178.0 x 161.0

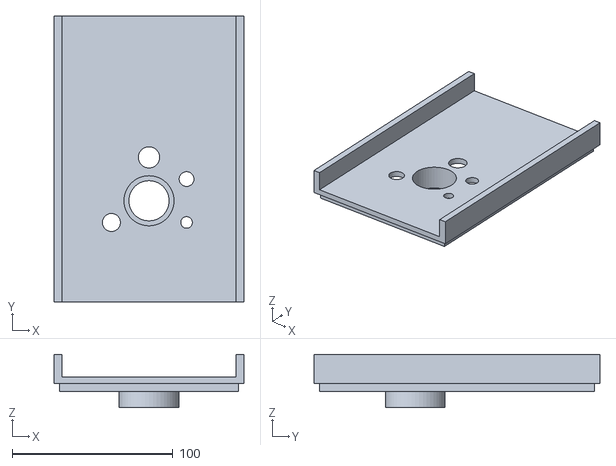
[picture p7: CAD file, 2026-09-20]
hardware/stl/wet_lid.stl
118.0 x 178.0 x 33.0

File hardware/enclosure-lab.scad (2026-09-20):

// ═════════════════════════════════════════════════════════════════════════════
//  Aqua Milk Detect — bench instrument
//  New file. Does not replace hardware/enclosure.scad; nothing here reads it.
//
//  ── What this is ────────────────────────────────────────────────────────────
//  A 140 × 200 × 320 monolith with three things you touch, each labelled in the
//  surface itself:
//
//      MILK              the sample drawer, middle of the front
//      DISTILLED WATER   the tank neck, top surface
//      WASTE             the tray, bottom of the front
//
//  The control surface is a facet cut off the front-top edge at 30°, because a
//  bench instrument is read from above and an ST7735 is a TN panel — vertical,
//  it washes out at exactly the angle you stand at. Display and touch pad live
//  behind one dark panel set into that facet.
//
//  ── The mechanism, and why it exists ────────────────────────────────────────
//  The probes hang ~100 mm down into the cup, so the cup cannot leave sideways
//  past them: something has to separate vertically first. The probe carriage is
//  therefore a plug that slides straight up in its socket. Down, its top face is
//  flush and the machine is a closed prism. Up, the cup is free and the drawer
//  opens.
//
//  The cup rides ON the drawer. Closing the drawer walks it up a 2 mm chamfer
//  onto the platform, so at rest the cup touches only the load cell and the
//  drawer clears it by 3 mm all round. That isolation is the whole reason the
//  density feature works.
//
//  ── One pump ────────────────────────────────────────────────────────────────
//  Fill only, from the internal tank. It is a PROBE RINSE, not a cup flush: the
//  cup is washed by hand, so water only ever has to run over the probes and fall
//  through the drawer's drain into the waste tray. A cup that cannot drain can
//  only dilute — 5 s of pumping removes about 5% of the milk in it — which is
//  why nothing here tries to flush a full cup.
//
//  ── Print notes ─────────────────────────────────────────────────────────────
//   part           orientation           supports  notes
//   base           as rendered (open up) no        140 × 200 — needs a 220 bed
//   bay            as rendered (open up) no        front is open by design
//   head           UPSIDE DOWN           no        facet then prints as a
//                                                  receding wall
//   carriage       as rendered           no
//   sample_drawer  as rendered (open up) no
//   waste_tray     as rendered (open up) no
//   platform       as rendered (flat)    no        6 perimeters, 60% infill
//   riser          as rendered (flat)    no        6 perimeters, 60% infill
//   tank_cap       as rendered (flat)    no
//
//  Engravings are RECESSED, never raised: raised text wears at the high points
//  and traps milk in its corners, while a 0.5 mm recess just holds a shadow.
//
//  Not printed: the cup (acrylic tube), the load cell, the dark facet panel, the
//  colour window, magnets, silicone tube, fasteners.
// ═════════════════════════════════════════════════════════════════════════════

part = "assembly";  // "assembly" | "base" | "bay" | "head" | "carriage" | "sample_drawer" | "waste_tray" | "platform" | "riser" | "tank_cap"

$fn = 64;

// ─────────────────────────────────────────────────────────────────────────────
//  1. Print / fit
// ─────────────────────────────────────────────────────────────────────────────
wall     = 3.0;
floor_t  = 3.0;
shelf_t  = 5.0;    // the load cell reacts against this
clr      = 0.35;   // sliding fits
eps      = 0.02;
merge    = 1.0;    // features sink this far into their parent, so unions share
                   // volume instead of touching on a tangent (the usual source
                   // of non-manifold geometry)

// ─────────────────────────────────────────────────────────────────────────────
//  2. The body
//     X width, Y depth (−Y is the front), Z up. Origin at the plan centre.
// ─────────────────────────────────────────────────────────────────────────────
body_w   = 140;
body_d   = 200;
base_h   = 125;    // tank feed, pump, boards, waste tray, load-cell shelf
bay_h    = 120;    // the loading bay: drawer, cup, water tank behind it
head_h   =  75;    // facet, display, carriage socket, tank neck
body_h   = base_h + bay_h + head_h;   // 320

in_w     = body_w - 2*wall;
in_d     = body_d - 2*wall;
y_front  = -in_d/2;
y_back   =  in_d/2;

// ─────────────────────────────────────────────────────────────────────────────
//  3. Surface language
// ─────────────────────────────────────────────────────────────────────────────
corner_r  = 12;    // superellipse corner size
sq_n      =  5;    // 2 is a circle; 5 is the continuous corner
sq_steps  = 20;

cut       = 1.2;   // the sharp cut on every visible edge
base_lift =   6;   // undercut band, so the body floats
base_in   =   3;
reveal    = 0.8;   // hairline between zones

facet_a   = 30;    // degrees from vertical — a bench is read from above
facet_h   = 62;    // measured up the slope
panel_t   = 2.0;   // dark panel set into the facet
panel_in  = 10;    // its inset from the facet edges

magnet_d  = 6.3;
magnet_h  = 3.2;

// ─────────────────────────────────────────────────────────────────────────────
//  4. Engraving
// ─────────────────────────────────────────────────────────────────────────────
eng_depth = 0.5;   // deep enough to hold a shadow, shallow enough to wipe clean
eng_size  = 5.5;   // cap height. Below ~4 mm a 0.4 nozzle cannot hold the stroke
eng_font  = "Liberation Sans:style=Bold";

// ─────────────────────────────────────────────────────────────────────────────
//  5. The cup (acrylic tube)
//     Specific gravity is grams / chamber_ml, so the dose only has to be
//     REPEATABLE. The weir enforces it: fill past it and the excess leaves.
// ─────────────────────────────────────────────────────────────────────────────
cup_id    = 70;
cup_wall  =  3;
cup_h     = 105;
dose_ml   = 175;
weir_d    =  6;

cup_od    = cup_id + 2*cup_wall;                          // 76
fill_mm   = dose_ml * 1000 / (PI * pow(cup_id/2, 2));     // 45.5
cup_x     = 0;
cup_y     = 15;    // rear of centre: the facet needs the front

// ─────────────────────────────────────────────────────────────────────────────
//  6. Probes and the carriage
//     The bore is set by the probes, not the volume: the turbidity body sits IN
//     the sample and the pH probe needs the annulus beside it.
//         cup_id >= turb_body_d + 2*(ph_probe_d + 2*probe_gap)
// ─────────────────────────────────────────────────────────────────────────────
turb_body_d = 38;  // MEASURE YOURS — it sets the bore, and the bore sets the cup
ph_probe_d  = 12;
tds_probe_d = 10;
ds18b20_d   =  6;
probe_gap   = 0.6;
probe_r     = 27;
ph_tip_gap  =  6;  // immersion = fill_mm - ph_tip_gap
feed_d      =  8;  // rinse nozzle
probe_a     = [90, 210, 330, 30, 150];   // pH, TDS, DS18B20, feed, spare
probe_d     = [ph_probe_d, tds_probe_d, ds18b20_d, feed_d, ds18b20_d];

car_d       = 95;  // carriage plug diameter
car_plate   =  6;
car_lift    = 60;  // how far it rises — must clear the probes from the cup
car_grip    = 26;  // finger relief in the top face

// ─────────────────────────────────────────────────────────────────────────────
//  7. Load cell (3 kg bar, TAL220 pattern)
// ─────────────────────────────────────────────────────────────────────────────
lc_len    = 80;
lc_w      = 12.7;
lc_h      = 12.7;
lc_pitch  = 15;
lc_span   = 55;
lc_hole_d = 4.5;
lc_nut_af = 8.1;
ped_h     = 15;
shelf_z   = 85;                       // top of the load-cell shelf, inside base
lc_free_z = shelf_z + ped_h + lc_h;   // top of the bar
plat_t    = 6;
plat_z    = 127;                      // platform underside
plat_top  = plat_z + plat_t;          // 133 — the cup's datum
plat_d    = cup_od - 8;               // pushes up THROUGH the drawer's pocket

// ─────────────────────────────────────────────────────────────────────────────
//  8. Drawers
// ─────────────────────────────────────────────────────────────────────────────
dr_w      = in_w - 6;
dr_d      = 170;
dr_h      = 22;      // tray depth; the cup stands proud of it
dr_floor  = 3;
dr_z      = 128;     // drawer floor top — 5 below the cup datum
dr_pocket = cup_od + 6;    // clears the cup by 3 mm all round at rest
dr_ramp   = 2;       // the chamfer that walks the cup onto the platform

wt_w  = in_w - 10;   // waste tray
wt_d  = 150;
wt_h  =  60;
wt_z  =  10;

// ─────────────────────────────────────────────────────────────────────────────
//  9. Water tank — behind the cup, filled from the top
// ─────────────────────────────────────────────────────────────────────────────
tank_y0  = cup_y + cup_od/2 + 8;     // starts clear of the cup
tank_w   = in_w - 8;
tank_h   = 100;
neck_d   = 34;
neck_y   = (tank_y0 + y_back)/2;
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

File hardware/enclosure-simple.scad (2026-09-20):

// ═════════════════════════════════════════════════════════════════════════════
//  Aqua Milk Detect — working enclosure
//  New file. Does not touch hardware/enclosure.scad or enclosure-lab.scad.
//
//  Built to the answers settled in the design interview. No styling, no
//  mechanism: a stepped two-bay tray, two lids, and the two load-cell parts.
//  Five printed pieces; the body prints in one go on a 220 bed.
//
//  ── Layout ──────────────────────────────────────────────────────────────────
//      WET BAY (left, tall)              DRY BAY (right, low)
//      cup on the load cell              pump on the floor
//      HX711 beside the cell             perfboard on rails above it
//      rinse nozzle on the rear wall     TFT + touch pad in the front wall
//      floor is the drip tray            USB + 12 V jack in the rear wall
//
//  A full-height partition separates them. Only four wires cross it (VCC, GND,
//  DT, SCK) plus the feed tube, and every crossing is HIGH on the wall — a
//  spilled 175 mL sample pools about 11 mm deep in the wet bay, and nothing at
//  that height can reach the electronics.
//
//  ── Why the walls differ ────────────────────────────────────────────────────
//  Wet bay 3.0 mm, dry bay and lids 2.4 mm. The load cell reacts against the
//  wet bay's frame, and a box that flexes shows up as tare drift in the density
//  reading. Nothing on the dry side cares, so those walls are thinner and
//  faster. Outer faces stay flush; the dry bay is simply 1.2 mm roomier inside.
//
//  ── Print notes ─────────────────────────────────────────────────────────────
//   part       orientation         supports  notes
//   body       as rendered         no        212 × 178 footprint
//   wet_lid    as rendered (flat)  no        parking feet print upward
//   dry_lid    as rendered (flat)  no
//   platform   as rendered (flat)  no        6 perimeters, 60% infill
//   riser      as rendered (flat)  no        6 perimeters, 60% infill
//
//  Not printed: the cup (acrylic tube), the load cell, the HX711, the perfboard,
//  the pump, silicone tube, fasteners.
// ═════════════════════════════════════════════════════════════════════════════

part = "assembly";  // "assembly" | "body" | "wet_lid" | "dry_lid" | "platform" | "riser"

$fn = 48;
eps = 0.02;

// ─────────────────────────────────────────────────────────────────────────────
//  1. Shell
//     Origin is the front-left-bottom OUTER corner. X right, Y back, Z up.
// ─────────────────────────────────────────────────────────────────────────────
w_wall  = 3.0;    // wet bay walls and the partition — the load path
d_wall  = 2.4;    // dry bay walls and both lids
floor_t = 3.0;

// Sized for a HAND, not for the cup. At 92 the cup had 8 mm of clearance per
// side and could not be gripped — you cannot lift a full cup of milk out of a
// slot that tight, and the cup comes out on every single test. 112 gives 18 mm
// per side, which is what fingers actually need.
wet_in_w = 112;
dry_in_w = 112;   // perfboard 102 + 5 mm each side
out_d    = 178;
wet_h    = 161;   // outer
dry_h    = 95;    // outer

wet_out_w = w_wall + wet_in_w + w_wall;          // 98, partition included
out_w     = wet_out_w + dry_in_w + d_wall;       // 212.4
wet_in_d  = out_d - 2*w_wall;                    // 172
dry_in_d  = out_d - 2*d_wall;                    // 173.2
part_x0   = w_wall + wet_in_w;                   // 95, partition inner face
part_x1   = wet_out_w;                           // 98, partition outer face

// ─────────────────────────────────────────────────────────────────────────────
//  2. Cup and load cell
//     Bore is set by the probes, not the volume: the turbidity body sits IN the
//     sample and the pH probe needs the annulus beside it.
//     Specific gravity is grams / chamber_ml, so the dose only has to be
//     REPEATABLE — that is what the weir does. Drill it at fill_mm above the
//     inside of the cup floor.
// ─────────────────────────────────────────────────────────────────────────────
cup_id   = 70;
cup_wall = 3;
// 70, not 105. The probes hang from the lid, and only the pH probe is long
// enough to reach down a tall cup: a 50 mm DS18B20 and a 60 mm TDS probe cannot
// span from the lid to the liquid at the bottom of a 105 mm cup. The fix is to
// bring the liquid UP to the lid instead — short cup, tall pedestal. See the
// reach echo below; it is the check that matters most in this file.
cup_h    = 70;
dose_ml  = 175;
cup_od   = cup_id + 2*cup_wall;                        // 76
fill_mm  = dose_ml * 1000 / (PI * pow(cup_id/2, 2));   // 45.5

cup_x = w_wall + wet_in_w/2;      // 49
cup_y = w_wall + 60;              // 63 — forward, leaving the rear for HX711

lc_len    = 80;    // 3 kg bar, TAL220 pattern
lc_w      = 12.7;
lc_h      = 12.7;
lc_pitch  = 15;    // hole-to-hole within one end
lc_span   = 55;    // centre of one hole pair to the other
lc_hole_d = 4.5;
lc_nut_af = 8.1;
ped_h     = 49.5;  // tall on purpose — it lifts the liquid into probe reach
ped_d     = 28;
ped_y     = cup_y + lc_span;                    // 118, fixed end
bar_z     = floor_t + ped_h;
plat_t    = 5;
plat_top  = floor_t + ped_h + lc_h + 12.3 + plat_t;   // 82.5, the cup's datum
riser_h   = plat_top - plat_t - (bar_z + lc_h); // 12.3
plat_d    = 80;    // cup ⌀76 plus a 2 mm locating ring; any bigger and it
                   // crowds the bay walls for no gain

hx_y = w_wall + 140;   // HX711 behind the cell, coated, bridge wires short
col_z = plat_top + cup_wall + fill_mm/2;   // colour sensor at mid-liquid

// ─────────────────────────────────────────────────────────────────────────────
//  3. Probes — carried by the wet lid
// ─────────────────────────────────────────────────────────────────────────────
// Turbidity sensor, from its datasheet: ⌀30 base plane, 34 tall overall, two
// arms 22 across with a 5.7 optical gap between them, photo-transistor and LED
// near the TOP of those arms, 3 pins on the base.
//
// The part is designed to mount in a tank floor with the arms pointing up. It
// cannot be used that way here: anything fixed to the cup is a force path into
// the weighed assembly. So it hangs INVERTED from the lid — arms down in the
// milk, pins up and dry — held in a printed collar that drops it far enough for
// the optical gap to submerge.
turb_body_d  = 30;   // base plane ⌀ — this is what sets the cup bore
turb_h       = 34;
turb_arm_w   = 22;
turb_optics  = 7;    // gap centre, measured up from the arm tips
turb_drop    = 15;   // how far the collar carries it below the lid
turb_lip     = 2;    // catches the ⌀30 base; the 22 mm arms pass through
ph_probe_d  = 12;
tds_probe_d = 10;
ds18b20_d   =  6;
probe_gap   = 0.6;
probe_r     = 27;
ph_tip_gap  =  6;   // immersion = fill_mm - ph_tip_gap
spare_d     =  8;   // spare gland

// ─────────────────────────────────────────────────────────────────────────────
//  4. Dry bay contents
// ─────────────────────────────────────────────────────────────────────────────
pb_w   = 102;   // perfboard, measured
pb_d   = 152;
pb_t   = 1.8;
pb_z   = 50;    // rail top — 7 mm over the pump, which varies between units
pb_y0  = 14;    // leaves room for the display in front of it

pump_w = 95;    // 6 V peristaltic, on the floor under the board
pump_d = 40;
pump_h = 40;

clip_w   = 16;  // corner clips that trap the board — no screws, no board holes
clip_t   = 3;
clip_lip = 2.5;

// ─────────────────────────────────────────────────────────────────────────────
//  5. Panel features
// ─────────────────────────────────────────────────────────────────────────────
tft_win_w  = 36.5;   // window for a 35.0 × 28.0 active area
tft_win_h  = 29.5;
tft_pcb_w  = 58;
tft_pcb_h  = 36;
tft_rebate = 1.5;
tft_hole_x = 51;     // 4 × M2 insert pattern
tft_hole_y = 29;
tft_x      = part_x1 + 42;
tft_z      = 68;

pad_w    = 20;       // TTP223 blind pocket — never a through hole
pad_h    = 16;
pad_wall = 1.2;      // plastic left in front of the pad
pad_x    = part_x1 + 92;
pad_z    = tft_z;

usb_w  = 15;         // panel-mount micro-USB, because the ESP32 is landlocked
usb_h  = 11;
usb_x  = part_x1 + 50;
jack_d = 8.2;
jack_x = part_x1 + 92;
port_z = 25;

vent_w     = 2.5;
vent_l     = 26;
vent_n     = 7;
vent_pitch = 6;

// Crossings sit in a window: high enough to clear a spill on the wet floor
// (a full 175 mL sample pools ~11 mm deep), but BELOW the dry bay's ceiling —
// the partition keeps rising past the dry bay to full wet height, so anything
// above dry_h opens into free air instead of into the electronics bay.
// One gland is oversized: the pH probe's cable ends in a BNC plug (~15 mm across
// the knurl) and the plug has to pass if you ever want to disconnect at the
// board rather than unthread the probe from the lid.
gland_z = 75;
glands  = [[w_wall + 128, 20], [w_wall + 150, 16]];
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

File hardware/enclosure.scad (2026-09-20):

// ═════════════════════════════════════════════════════════════════════════════
//  Aqua Milk Detect — enclosure, Rev C
//  Companion to docs/enclosure.md and docs/wiring.md.
//
//  A single squircle tower, 126 × 136 × 220, with a telescoping column. 3.8 L
//  against Rev B's 12.4 — seventy percent smaller — because the electronics went
//  UNDER the cup instead of beside it, which also deleted the two-shell split
//  and with it every seam that ran up the sides.
//
//  ── What is open to the outside, exhaustively ──────────────────────────────
//    · the pour dish on the column cap            engraved MILK
//    · the tank neck on the top plate             engraved DISTILLED WATER
//    · the drawer aperture on the front
//    · one USB-C port, centred on the rear
//    · intake slots, underside only
//  That is the whole list. Everything else visible in an OpenSCAD PREVIEW —
//  ledges, bosses, ribs, interiors showing green — is internal structure seen
//  through the translucent fascia mock. Press F6 (or export an STL) and the body
//  is a closed shell.
//
//  ── The mechanism, and why it has to exist ─────────────────────────────────
//  The probes hang into the cup, so the cup cannot slide out horizontally past
//  them: something must separate vertically first. The column is therefore its
//  own piston, sliding 55 mm in a socket in the top plate. Lift it, the cup is
//  free; pull the drawer, dump it, push it back, drop the column.
//  The column is mechanically isolated from the load cell — if it ever binds it
//  cannot put a gram into the reading.
//
//  The cup rides ON the drawer plate. Closing the drawer walks the cup up a
//  1.5 mm chamfer onto the platform, so at rest the cup touches only the load
//  cell, and the plate's ⌀78 hole clears it by 4 mm all round.
//
//  ── One pump ───────────────────────────────────────────────────────────────
//  Fill only. Distilled water from the internal tank, over the probes, into the
//  cup — its job is rinsing the sensors, not emptying the machine. You empty the
//  machine by pulling the drawer. No drain pump, no dip tube, and no vent hole:
//  the pour dish vents.
//
//  ── Print notes ─────────────────────────────────────────────────────────────
//   part          orientation             supports  notes
//   body          as rendered (open up)   no        needs 220 mm Z
//   top_plate     as rendered (flat)      no        carries both engravings
//   shelf         as rendered (flat)      no        load-cell datum: 6 perimeters,
//                                                   60% infill, no less
//   column        as rendered (tube up)   no
//   column_cap    UPSIDE DOWN (dish down) no        duct then prints upward
//   drawer        as rendered (open up)   no
//   cup           as rendered (open up)   no        5 perimeters — it holds liquid
//   tank          as rendered (open up)   no        5 perimeters, and a silicone
//                                                   bead on the lid seam or it
//                                                   weeps into the electronics
//   tank_lid      as rendered (flat)      no
//   platform      as rendered (flat)      no        6 perimeters, 60% infill
//   riser         as rendered (flat)      no
//
//  Finish: 0.10–0.12 mm layers. Matte PETG, not PLA — PLA creeps under a bolted
//  load cell and does not survive repeated cleaning. A squircle only reads as a
//  squircle when the layer lines disappear into the curve.
//
//  Not printed: the load cell, the smoked acrylic fascia, the colour window,
//  magnets, silicone tube, four M4 bolts.
// ═════════════════════════════════════════════════════════════════════════════

part = "assembly";  // "assembly" | "body" | "top_plate" | "shelf" | "column" | "column_cap" | "drawer" | "cup" | "tank" | "tank_lid" | "platform" | "riser"

column_lifted = false;   // true previews the column raised, cup clear of probes
section       = false;   // true cuts the assembly on the centreline, so you can
                         // see the milk path and where the probes actually sit

$fn = 72;

// ─────────────────────────────────────────────────────────────────────────────
//  1. Print / fit
// ─────────────────────────────────────────────────────────────────────────────
wall          = 3.0;
floor_t       = 4.0;
clr           = 0.3;
eps           = 0.02;
merge         = 1.0;    // every feature sinks this far into its parent, so
                        // unions share volume instead of touching on a tangent
reveal        = 0.45;   // uniform seam gap; below this a 0.4 nozzle bridges it

// ─────────────────────────────────────────────────────────────────────────────
//  2. The squircle
// ─────────────────────────────────────────────────────────────────────────────
sq_n          = 5;
sq_steps      = 96;
shoulder      = 6;      // G2 top-edge blend
shoulder_n    = 3;
shoulder_step = 16;

// ─────────────────────────────────────────────────────────────────────────────
//  3. Envelope
// ─────────────────────────────────────────────────────────────────────────────
body_w        = 126;
body_d        = 136;
body_h        = 220;
base_inset    = 3;      // undercut, so the tower floats
base_h        = 6;

in_w          = body_w - 2*wall;    // 120
in_d          = body_d - 2*wall;    // 130
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

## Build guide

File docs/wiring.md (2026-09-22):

# Wiring

Every connection, plus the two places this build differs from the naive one. Pin
assignments are authoritative in
[`libs/AquaMilkSensors/src/pins.h`](../libs/AquaMilkSensors/src/pins.h) and
`PROJECT_CONTEXT.md` §3.

## Signal map

flowchart TB
  subgraph esp["ESP32-WROOM-32 DevKit V1"]
    direction LR
    A36["GPIO36 ADC1_CH0"]:::in
    A39["GPIO39 ADC1_CH3"]:::in
    A34["GPIO34 ADC1_CH6"]:::in
    I2C["GPIO21/22 I²C"]
    OW["GPIO4 OneWire"]
    HX["GPIO16/17"]
    SPI["GPIO18/23 + 5/2/15"]
    PWM["GPIO25 digital"]
    TCH["GPIO27 RTC"]
  end

  PH["pH board<br/>0–5 V out"] -->|2:1 divider| A36
  TDS["Gravity TDS<br/>0–2.3 V out"] --> A39
  TURB["Turbidity module<br/>0–4.5 V out"] -->|2:1 divider| A34
  COL["TCS34725"] --- I2C
  DS["DS18B20<br/>4.7 kΩ to 3V3"] --- OW
  TFT["ST7735 128×160"] --- SPI
  PWM --> M["3.3 V relay module"] --> P["6 V pump"]
  PAD["TTP223 pad"] --> TCH

  classDef in fill:#0FB5C9,color:#fff,stroke:none;

## Connection list

### Analog (all on ADC1 — ADC2 is dead while Wi-Fi runs)

| From | To | Notes |
|---|---|---|
| pH board signal | divider → GPIO36 | Board output can approach 5 V. **Divider required.** |
| pH board VCC / GND | 5 V / GND | Common ground with the ESP32 or readings wander |
| TDS signal | GPIO39 | Output stays under 2.4 V, so a divider is optional (`div_tds = 1.0`) |
| TDS VCC / GND | 5 V / GND | |
| Turbidity signal | divider → GPIO34 | 0–4.5 V output. **Divider required.** |
| Turbidity VCC / GND | 5 V / GND | |

A 2:1 divider is two equal resistors (10 kΩ + 10 kΩ) from signal to ground, tapped in the
middle. Measure what you actually built and enter the ratio on the Calibrate page — the
firmware multiplies the pin voltage by it, so a wrong ratio silently scales every reading
and therefore every feature the model sees.

GPIO36/39/34 are **input-only** pins. That is fine here and is why they were chosen.

### Digital

| From | To | Notes |
|---|---|---|
| TCS34725 SDA / SCL | GPIO21 / GPIO22 | 3V3 power. Most breakouts have pull-ups fitted |
| DS18B20 data | GPIO4 | **4.7 kΩ pull-up from data to 3V3** — without it, -127 °C |
| DS18B20 VCC / GND | 3V3 / GND | |
| TFT SCLK / MOSI | GPIO18 / GPIO23 | VSPI |
| TFT CS / DC / RST | GPIO5 / GPIO2 / GPIO15 | DC/RST on strapping pins — pull the DevKit from its socket to flash, then reseat |
| TFT LED / BL | 3V3 | Move to GPIO32 if you want PWM dimming |
| (no touch pad) | GPIO27 free | TTP223 removed — the device is controlled from the browser dashboard |

### Pump

The 6 V pump is switched by a **3.3 V relay module**, driven straight from the ESP32:

```
GPIO25 ──── relay IN
3V3    ──── relay VCC
GND    ──── relay GND

relay COM / NO ──── in series with the pump's +6 V feed
```

The module has its own driver transistor and flyback diode on board, so GPIO25 sources
almost no current and **no 2N2222 level-shifter is needed** — that is the whole point of
using a relay here instead of the bare IRF520.

This module is **active-HIGH**: driving IN high energizes the coil, so **GPIO HIGH = pump
ON**. The firmware knows this via `PUMP_ACTIVE_LOW` (default `false`) in
[`sensors.h`](../libs/AquaMilkSensors/src/sensors.h). Drive it as a plain digital output —
**never PWM a relay**, or the coil chatters. Symptom check: if the pump runs continuously
at idle and stops when you press *Flush test*, your module is active-LOW — set the flag
`true` and rebuild.

A relay's contacts switch the inductive motor cleanly, but a **1N4007 flyback diode across
the pump** (band → +6 V) is still cheap insurance against contact arcing; keep it if you
have one fitted.

## Power

```mermaid
flowchart LR
  ADP["12 V 1.5 A<br/>(18 W)"] --> B1["LM2596 #1<br/>set to 6.0 V"] --> PUMP["Pump ≈ 3 W"]
  ADP --> B2["LM2596 #2<br/>set to 5.0 V"] --> ESP["ESP32<br/>5V pin"]
  ESP --> LDO["on-board 3V3"] --> D3["TFT, TCS34725,<br/>DS18B20"]
  B2 --> A5["pH / TDS / turbidity<br/>boards at 5 V"]
```

Rough budget: ESP32 with Wi-Fi transmitting peaks around 500 mA at 3.3 V, the pump draws
a few hundred mA at 6 V, everything else is tens of milliamps. The 18 W adapter is ample;
the thing that actually matters is that **all grounds are common** and that the pump's
current does not return through a thin jumper shared with the analog sensors' ground —
that is what makes pH readings jump every time the pump kicks in. Run the pump ground
straight back to the buck converter.

Set both LM2596 outputs with a multimeter **before** connecting anything. They ship at
arbitrary voltages, and 12 V into the ESP32's 5 V pin ends the project.

## Fluidics

Silicone tube from the distilled-water reservoir → pump → test chamber, and chamber →
waste cup. The chamber sits on the load cell, so nothing else may touch it: a tube pulling
on the chamber shows up as grams, which the model reads as density. Route tubing with a
loose loop and clamp it to the enclosure, not to the chamber.

## Bring-up order

1. Set both buck converters with a multimeter. Nothing else connected.
2. ESP32 + TFT only. Flash stage 1, confirm the display shows "Calibration mode".
3. Add sensors one at a time, checking *Test all sensors* after each. A flag that stays
   false is that sensor's wiring — not calibration.
4. Add the pump path last, and test it with *Flush test* before any liquid is in the tube.
5. Only then start the calibration walkthrough in
   [01_calibration/README.md](../01_calibration/README.md).

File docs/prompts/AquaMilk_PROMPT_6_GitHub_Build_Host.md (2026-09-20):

# AGENT PROMPT 6 — GitHub Repo, Auto-Build & Hosting (`.github/`, repo)

**Read `PROJECT_CONTEXT.md` first (repo layout §10, conventions §11). This wires everything together so the user's connected GitHub account builds the firmware `.bin`s and hosts the web app automatically.**

## Your task
Create the repository **`aquamilk-detect`** under the user's connected GitHub account with the layout in §10, an MIT license, a great README, and **GitHub Actions** that (a) compile the three Arduino sketches to `.bin` and (b) deploy the web app to **GitHub Pages** — so browser-flashing and the hosted UI "just work."

## Repo setup
- Create repo `aquamilk-detect` (public, MIT, author Nikhil). Add `PROJECT_CONTEXT.md` at root (from this project). Folders per §10.
- `README.md`: project intro + tagline, the **wiring guide** (pin map §3 as a table + a note on the ADC dividers §3 and the **3.3 V relay pump switching** §4), power diagram, the three-stage workflow, how to flash from the web app, how to collect data, how to train, and how to run the deployed device (SoftAP/`aquamilk.local`). Generate a simple wiring diagram (Mermaid or an SVG in `docs/`).

## Workflow A — build firmware (`.github/workflows/build-firmware.yml`)
- Trigger on push to `main` touching `01_*`, `02_*`, `03_*`, or manual `workflow_dispatch`.
- Use **`arduino-cli`**: install core `esp32:esp32` (pin a known-good version), install the libraries listed in the firmware prompts (ArduinoJson, Adafruit_TCS34725, Adafruit_GFX, Adafruit_ST7735 or TFT_eSPI, OneWire, DallasTemperature, HX711, DFRobot GravityTDS, ESPAsyncWebServer, AsyncTCP; pin versions).
- Compile each sketch (`arduino-cli compile --fqbn esp32:esp32:esp32 --output-dir ...`) and copy the merged `.bin` into `web/firmware/` as `calibration.bin`, `collection.bin`, `deployment.bin`.
- Generate/refresh **ESP Web Tools manifests** `web/firmware/<name>-manifest.json` (correct chipFamily `ESP32`, offset, path).
- Commit the built bins back (or pass them as artifacts into the Pages job). Fail loudly if any sketch doesn't compile.

## Workflow B — deploy web (`.github/workflows/deploy-web.yml`)
- Trigger on push touching `web/` (and after Workflow A). Build the web app (if it uses a bundler: `npm ci && npm run build`), then **deploy to GitHub Pages** (`actions/deploy-pages`). Ensure `web/firmware/*` (bins + manifests) are included in the published site so ESP Web Tools can fetch them from HTTPS.
- Output the Pages URL in the job summary.

## Notes / quality bar
- Everything must end up served over **HTTPS** (GitHub Pages) — required for Web Serial + ESP Web Tools.
- Pin all tool/core/library versions for reproducible builds; cache where sensible.
- Keep `model.h`/`scaler.h` as committed stubs so `03_deployment` compiles in CI before training; document that the user replaces them after running the trainer, which re-triggers the firmware build.
- Add a `CONTRIBUTING`/short dev note and badges (build passing, Pages) in the README.

## Deliverables
The created repo with `.github/workflows/build-firmware.yml`, `.github/workflows/deploy-web.yml`, `LICENSE` (MIT), root `README.md` with wiring + workflow, `docs/` wiring diagram, and confirmation that both workflows pass and the Pages site is live. Report the final **Pages URL** and the three firmware manifest URLs.

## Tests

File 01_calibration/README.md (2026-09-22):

# Stage 1 — Calibration & test firmware

Reads every sensor, calibrates each one, and stores the constants in the ESP32's NVS
so Stages 2 and 3 inherit them. Driven from the **Calibrate** page of the web app over
USB Web Serial. No Wi-Fi in this firmware.

## Flash it

From the web app (easiest): **Flash → Calibration firmware** in desktop Chrome/Edge. The
page does not need a COM port — Chrome asks you to pick the device.

From the command line. Check your port with `arduino-cli board list`; the `COM5` below is
just an example:

```bash
arduino-cli compile --fqbn esp32:esp32:esp32 --libraries libs 01_calibration
```

```bash
arduino-cli upload -p COM5 --fqbn esp32:esp32:esp32 01_calibration
```

`--libraries libs` is what makes `#include <sensors.h>` resolve — the shared sensor
code lives in [libs/AquaMilkSensors](../libs/AquaMilkSensors) so all three firmwares
compile the *same* file instead of three drifting copies. Using the Arduino IDE
instead? Copy `libs/AquaMilkSensors` into your `Arduino/libraries/` folder once.

## Command list

| Command | What it does |
|---|---|
| `{"cmd":"get_cal"}` | Return the stored constants as `{"t":"cal",…}` |
| `{"cmd":"calibrate","sensor":"ph","point":7.0}` | Capture the current mV as the pH 7.0 point |
| `{"cmd":"calibrate","sensor":"ph","point":4.0}` | Capture pH 4.0; with both points it fits slope + offset and leaves raw mode |
| `{"cmd":"set","key":"ph_mode","val":"raw"}` | Skip pH calibration entirely, report raw mV |
| `{"cmd":"calibrate","sensor":"tds","known_ppm":707}` | Solve the K factor against a known solution (omit for the stock curve) |
| `{"cmd":"calibrate","sensor":"turbidity","point":"clear"}` | Current reading becomes the clear-water zero |
| `{"cmd":"calibrate","sensor":"color","point":"white"}` | Capture the white reference |
| `{"cmd":"tare"}` | Zero the load cell with the chamber empty |
| `{"cmd":"flush","ms":5000}` | Run the pump to test the flush path |
| `{"cmd":"selftest"}` | All sensors at once → `{"t":"selftest",…}` with a flag per sensor |
| `{"cmd":"set","key":…,"val":…}` | `oversample`, `div_ph`, `div_tds`, `div_turb`, `avg_ms`, `flush_ms`, `conf_thr` |
| `{"cmd":"factory_reset"}` | Wipe NVS back to defaults |

Every command is acked with `{"t":"ack","cmd":…,"ok":…,"msg":…}`, and anything that
changes calibration is followed by a fresh `{"t":"cal",…}` snapshot. Readings stream
at ~5 Hz as `{"t":"reading",…}`: `ph`/`tds`/`turb` are **millivolts at the sensor
board** (divider already applied), and `calc.{ph,ppm,ntu,sg}` are the human-readable
conversions.

## Calibration walkthrough

Do these in order, with the web app's Calibrate page open.

1. **Dividers first.** Any sensor board that can swing above 3.3 V needs a resistor
   divider (§3): turbidity 0–4.5 V and the pH board both do. Measure your actual
   divider with a multimeter and set the ratio (`div_ph`, `div_turb`, `div_tds`) —
   2.0 means "the pin sees half of what the board puts out". Everything downstream
   assumes this is right.
2. **Selftest.** Hit *Test all sensors*. Every flag should be true. A false flag is a
   wiring problem, not a calibration problem — fix it before continuing.
3. **Turbidity zero.** Fill the chamber with distilled water → *set clear-water zero*.
5. **Colour white reference.** Same clear water (or a white card against the sensor)
   → *set white reference*.
6. **pH, if you have buffers.** Rinse the probe, sit it in pH 7.0 → capture 7.0;
   rinse, sit in pH 4.0 → capture 4.0. Two good points switch the firmware out of raw
   mode. **No buffers? Leave raw mode on** — the model trains on raw millivolts either
   way (see `features.h`), so skipping this costs you the human-readable pH number,
   not accuracy.
7. **Flush test.** Hit *Flush test*. The pump is switched by a **3.3 V relay module**
   on GPIO25. This build's module is **active-HIGH**, so `PUMP_ACTIVE_LOW` defaults to
   `false` in `sensors.h`. If the pump instead runs constantly at idle and stops when
   you command a flush, your module is active-LOW — set that flag `true` and rebuild.
   Never PWM a relay; see §4 of `PROJECT_CONTEXT.md`.

Constants are written to NVS (namespace `amd_cal`) the moment each step succeeds, so
you can power-cycle mid-way through without losing work.

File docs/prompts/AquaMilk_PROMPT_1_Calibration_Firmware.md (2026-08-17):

# AGENT PROMPT 1 — Calibration & Test Firmware (`01_calibration/`)

**Read `PROJECT_CONTEXT.md` first and obey it (pin map §3, ADC rules §3, power/pump §4, protocol §8, conventions §11). Use any skills that help (e.g. the skill-creator/docs skills for the README).**

## Your task
Write an **Arduino (ESP32, arduino-esp32 core)** sketch named `01_calibration.ino` that lets the user **read and calibrate every sensor individually and all at once**, driven from the web app over **USB Web Serial** using the JSON protocol in §8. Store calibration constants in NVS (`Preferences`, namespace `"amd_cal"`). This firmware never uses Wi-Fi.

## Sensors to support (pins from §3)
pH (GPIO36), TDS (GPIO39), turbidity (GPIO34) — all ADC1, use `analogReadMilliVolts`, `ADC_11db`, oversample (e.g. 64 reads, discard outliers, average). TCS34725 (I²C 21/22, Adafruit_TCS34725). DS18B20 (OneWire GPIO4, DallasTemperature). HX711 (DOUT16/SCK17, HX711 lib). TFT ST7735 (SPI, Adafruit_ST7735 or TFT_eSPI — pick one and pin it in a comment) for a local status readout.

## Behaviour
1. **Boot:** init all sensors, load saved calibration from NVS (defaults if none). Show "Calibration mode" + connection hint on the TFT.
2. **Stream readings** at ~5 Hz as `{"t":"reading",...}` (all raw + calibrated values). Also mirror a compact live view on the TFT.
3. **Handle commands** (ack every one with `{"t":"ack",...}`):
   - `{"cmd":"calibrate","sensor":"ph","point":7.0}` and `...,"point":4.0}` → **2-point pH cal**: capture current mV at each point, compute slope+offset (mV→pH), save. Support a **"raw/skip" mode** (`{"cmd":"set","key":"ph_mode","val":"raw"}`) that bypasses cal and reports raw mV — because the user may skip buffers.
   - `{"cmd":"calibrate","sensor":"tds"}` → run `GravityTDS` calibration against a known solution if provided, else keep library default; expose K factor.
   - `{"cmd":"calibrate","sensor":"turbidity","point":"clear"}` → set clear-water zero reference.
   - `{"cmd":"calibrate","sensor":"color","point":"white"}` → capture white reference for normalization.
   - `{"cmd":"tare"}` → zero the load cell (empty chamber).
   - `{"cmd":"calibrate","sensor":"density","known_g":100.0}` → set span with a known weight → compute scale factor.
   - `{"cmd":"set","key":"...","val":...}` → adjustable params (oversample count, adc divider ratios per analog channel, flush ms).
   - `{"cmd":"flush","ms":5000}` → pulse the pump (respect `PUMP_ACTIVE_LOW` from §4) to test the flush path.
   - `{"cmd":"selftest"}` → run an **all-sensors-at-once** health check: confirm each sensor responds, values in plausible range; return `{"t":"selftest",...ok flags...}`.
4. **Persistence:** every successful calibration writes to NVS immediately and returns the stored constants so the UI can display them. A `{"cmd":"factory_reset"}` clears NVS.

## Requirements / quality bar
- Non-blocking loop (no `delay` in the stream path); robust JSON parsing (ArduinoJson) that ignores malformed lines.
- Each analog channel has a **configurable divider ratio** constant (see §3 ADC note) applied before reporting mV→sensor units.
- Clear serial banner on boot with firmware name + version + build date.
- A shared `sensors.h/.cpp` module (read + calibrate + apply) so `02_collection` and `03_deployment` can reuse the exact same code — **factor sensor code into reusable files**.
- Comment the chosen TFT library + wiring; keep pins matching §3.
- Provide a short in-sketch header comment listing the JSON commands.
- Include `library requirements` (names + versions) as a comment block for CI to install: `ArduinoJson, Adafruit_TCS34725, OneWire, DallasTemperature, HX711, Adafruit_ST7735 (+Adafruit_GFX) or TFT_eSPI, DFRobot GravityTDS`.

## Deliverables
`01_calibration/01_calibration.ino`, `01_calibration/sensors.h`, `01_calibration/sensors.cpp`, and a short `01_calibration/README.md` (what it does, how to flash, the command list, calibration walkthrough). Verify it compiles under arduino-cli for `esp32:esp32:esp32`.

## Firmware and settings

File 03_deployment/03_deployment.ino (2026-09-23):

/*
  03_deployment.ino — Aqua Milk Detect, Stage 3: the finished standalone tester.
  ESP32 DevKit V1 (arduino-esp32 core). Runs the trained SVM on-device, shows the
  verdict on the TFT, serves its own Wi-Fi dashboard, self-flushes, driven by one
  TTP223 pad, with soft-power deep sleep.

  ------------------------------------------------------------------- gestures (§7)
    single tap ............ run a test
    double tap ............ flush now
    long press ~1.5 s ..... on-screen menu (tap = next item, double tap = select,
                            long press = exit). Items: Wi-Fi info,
                            Re-check calibration, Settings, Gestures, Exit.
    tap, tap, hold ........ soft power: deep sleep. Touch wakes it (ext0 on GPIO27).

  ------------------------------------------------------------------ HTTP endpoints
    GET  /                  gzipped dashboard from PROGMEM (dashboard.h)
    GET  /api/state         settings + Wi-Fi + last verdict + model status
    GET  /api/log           rolling log from LittleFS  {"rows":[{ms,cls,conf,ph,...}]}
    POST /api/test          start a test
    POST /api/flush         flush now
    POST /api/selftest      all-sensors health check -> {"ok":bool,"why":".."}
    POST /api/settings      ?thr=&flush_ms=&avg_ms=
    POST /api/wifi          ?mode=ap|sta&ssid=&pass=   (saves, then reboots)
    POST /api/factory_reset clears NVS calibration + settings + Wi-Fi, wipes the log

  ---------------------------------------------------------------- WebSocket /ws
    {"t":"reading", ph,tds,turb,temp,r,g,b,c, calc:{ph,ppm,ntu}}   ~2 Hz
    {"t":"status",  state:"idle"|"testing"|"flushing"}
    {"t":"result",  cls, conf, uncertain, adulterated, p_adult, probs{}, z[], reason, ms}

  ------------------------------------------------------------------- feature order
    [ph, tds, turbidity, temperature, color_r, color_g, color_b, color_clear]
    Defined once in libs/AquaMilkSensors/src/features.h and mirrored by the trainer.
    model.h + scaler.h are generated by training/train.py; the committed ones are
    placeholders that always answer "Uncertain" (MODEL_IS_PLACEHOLDER).

  Timestamps are milliseconds since boot — there is no RTC on the board, so the
  dashboard renders them as relative times instead of pretending to know the date.

  Libraries: pinned set from 01_calibration plus ESP Async WebServer 3.12.0 +
  Async TCP 3.4.9 (ESP32Async). Shared sensor code: libs/AquaMilkSensors.
*/

#include <WiFi.h>
#include <ESPmDNS.h>
#include <DNSServer.h>
#include <LittleFS.h>
#include <Preferences.h>
#include <ArduinoJson.h>
#include <ESPAsyncWebServer.h>

#include <sensors.h>
#include <serialio.h>
#include <display.h>
#include "svm_infer.h"
#include "dashboard.h"

#define FW_NAME "03_deployment"
#define FW_VER  "1.0.0"

#define LOG_PATH  "/log.csv"
#define LOG_KEEP  200          // rolling log length (§11)

// ------------------------------------------------------------------ app state
enum AppState { IDLE, TESTING, FLUSHING };
static AppState  app = IDLE;
static AsyncWebServer server(80);
static AsyncWebSocket ws("/ws");
static DNSServer  dnsServer;             // captive portal: all lookups -> AP IP
static bool       captive = false;       // true only in SoftAP mode
static Preferences net_prefs;

static Verdict  last_v;
static bool     have_result = false;
static uint32_t last_ms = 0;
static char     reason[64] = "";

static String   ap_ssid, ap_pass, sta_ssid, sta_pass, ip_str;
static bool     sta_mode = false;
static uint32_t t_push = 0, t_tft = 0;

// ------------------------------------------------------------------- log (fs)
static void logAppend(const Verdict& v, const Reading& r) {
  File f = LittleFS.open(LOG_PATH, FILE_APPEND);
  if (!f) return;
  f.printf("%lu,%s,%.3f,%.0f,%.0f,%.0f,%.1f\n",
           (unsigned long)millis(),
           v.uncertain ? "uncertain" : CLASS_NAMES[v.cls],
           v.conf, r.ph_mv, r.tds_mv, r.turb_mv, r.temp_c);
  size_t sz = f.size();
  f.close();

  if (sz < 12000) return;             // ~240 rows of ~50 B — trimming is rare
  File in = LittleFS.open(LOG_PATH, FILE_READ);
  if (!in) return;
  String all = in.readString();
  in.close();
  int keep_from = 0, seen = 0;
  for (int i = all.length() - 1; i >= 0; i--) {
    if (all[i] == '\n') {
      seen++;
      if (seen > LOG_KEEP) { keep_from = i + 1; break; }
    }
  }
  File out = LittleFS.open(LOG_PATH, FILE_WRITE);
  if (out) { out.print(all.substring(keep_from)); out.close(); }
}

// ponytail: /api/log streams the log file as-is. Rewriting those CSV lines into JSON on
// the ESP32 cost 35 lines of substring surgery to produce something the dashboard then
// re-split anyway — it already parses CSV for the export button.

// --------------------------------------------------------------------- pushes
static void pushStatus() {
  JsonDocument d;
  d["t"] = "status";
  d["state"] = app == TESTING ? "testing" : app == FLUSHING ? "flushing" : "idle";
  String s;
  serializeJson(d, s);
  ws.textAll(s);
}

static void fillResult(JsonDocument& d) {
  d["t"] = "result";
  d["cls"] = last_v.uncertain ? "uncertain" : CLASS_NAMES[last_v.cls];
  d["conf"] = last_v.conf;
  d["uncertain"] = last_v.uncertain;
  d["adulterated"] = last_v.adulterated;
  d["p_adult"] = probAdulterated(last_v);
  d["reason"] = reason;
  d["ms"] = last_ms;
  JsonObject p = d["probs"].to<JsonObject>();
  for (uint8_t c = 0; c < CLASS_COUNT; c++) p[CLASS_NAMES[c]] = last_v.prob[c];
  JsonArray z = d["z"].to<JsonArray>();
  for (uint8_t f = 0; f < FEATURE_COUNT; f++) z.add(last_v.z[f]);
}

static void pushReading() {
  JsonDocument d;
  readingJson(d);
  String s;
  serializeJson(d, s);
  ws.textAll(s);
}

static void pushResult() {
  JsonDocument d;
  fillResult(d);
  String s;
  serializeJson(d, s);
  ws.textAll(s);
}

// ------------------------------------------------------------------------ TFT
static void tftIdle() {
  const Reading& r = sensorsLatest();
  static char v_ssid[22], v_ip[22], v_pass[22], v_col[16];
  snprintf(v_ssid, sizeof v_ssid, "%s", (sta_mode ? sta_ssid : ap_ssid).c_str());
  snprintf(v_ip,   sizeof v_ip,   "%s", ip_str.c_str());
  snprintf(v_pass, sizeof v_pass, "%s", sta_mode ? "aquamilk.local" : ap_pass.c_str());
  snprintf(v_col,  sizeof v_col,  "%u/%u/%u", r.r, r.g, r.b);

  const char* keys[] = { "Wi-Fi", sta_mode ? "Host" : "Password", "Address", "Model", "Colour" };
  const char* vals[] = { v_ssid, v_pass, v_ip,
#if MODEL_IS_PLACEHOLDER
                         "none",
#else
                         "ready",
#endif
                         v_col
                       };
  dispKV("Control from dashboard", keys, vals, sizeof(keys) / sizeof(keys[0]));
}

static void tftVerdict() {
  uint16_t col = last_v.uncertain ? AMD_AMBER : (last_v.adulterated ? AMD_RED : AMD_GREEN);
  char sub[40];
  snprintf(sub, sizeof sub, "%d%% confident", (int)lroundf(last_v.conf * 100));
  const char* word = last_v.uncertain ? "Uncertain" : CLASS_NAMES[last_v.cls];
  dispBig(word, col, sub);
  // Confidence as a bar under the word, then the binary headline and the two channels
  // that moved most — the hierarchy is verdict, certainty, why.
  dispBar((uint8_t)lroundf(last_v.conf * 100), col, 104);
  Adafruit_ST7735& t = dispTft();
  t.setTextSize(1);
  t.setTextColor(last_v.uncertain ? AMD_AMBER : col);
  t.setCursor(4, 118);
  t.print(last_v.uncertain ? "Retest / flush" : (last_v.adulterated ? "ADULTERATED" : "PURE"));
  t.setTextColor(AMD_MUTED);
  t.setCursor(4, 134);
  t.print(reason);
}

// ------------------------------------------------------------------ test flow
static void startTest() {
  if (app != IDLE) return;
  app = TESTING;
  avgStart(cal.avg_ms);
  dispBig("Reading", AMD_ACCENT, "hold still");
  pushStatus();
}

static void finishTest() {
  AveragedSample s = avgFinish();
  if (!s.ok) { app = IDLE; pushStatus(); return; }

  last_v = svmClassify(s.mean, cal.conf_threshold);
  last_ms = millis();
  have_result = true;
#if MODEL_IS_PLACEHOLDER
  snprintf(reason, sizeof reason, "no model on device");
#else
  snprintf(reason, sizeof reason, "%s %+.1f sd, %s %+.1f sd",
           FEATURE_NAMES[last_v.top_feat[0]], last_v.z[last_v.top_feat[0]],
           FEATURE_NAMES[last_v.top_feat[1]], last_v.z[last_v.top_feat[1]]);
#endif

  logAppend(last_v, sensorsLatest());
  pushResult();
  tftVerdict();

  app = IDLE;                       // no auto-flush; flush manually from the dashboard
  pushStatus();
}

// Control is entirely via the Wi-Fi dashboard now (no TTP223 touch pad). A test is
// started by POST /api/test -> startTest(); flush/selftest/settings/wifi/
// factory_reset each have their own endpoint (see routes()). Deep sleep was removed
// with the touch pad, since nothing was left to wake the device.

// ---------------------------------------------------------------------- Wi-Fi
static void netLoad() {
  net_prefs.begin("amd_net", true);
  sta_ssid = net_prefs.getString("ssid", "");
  sta_pass = net_prefs.getString("pass", "");
  sta_mode = net_prefs.getBool("sta", false) && sta_ssid.length() > 0;
  net_prefs.end();
}

static void netStart() {
  uint8_t mac[6];
  WiFi.macAddress(mac);
  char id[5];
  snprintf(id, sizeof id, "%02X%02X", mac[4], mac[5]);
  ap_ssid = String("AquaMilk-") + id;
  ap_pass = String("aqua-") + id;          // 9 chars, shown on the TFT

  if (sta_mode) {
    WiFi.mode(WIFI_STA);
    WiFi.begin(sta_ssid.c_str(), sta_pass.c_str());
    uint32_t t0 = millis();
    while (WiFi.status() != WL_CONNECTED && millis() - t0 < 12000) delay(200);
    if (WiFi.status() == WL_CONNECTED) {
      ip_str = WiFi.localIP().toString();
      if (MDNS.begin("aquamilk")) MDNS.addService("http", "tcp", 80);
      return;
    }
    sta_mode = false;                       // fall back so the device is never unreachable
  }
  WiFi.mode(WIFI_AP);
  WiFi.softAP(ap_ssid.c_str(), ap_pass.c_str());
  ip_str = WiFi.softAPIP().toString();

  // Captive portal: answer every DNS query with our own IP, so the phone's
  // connectivity check is redirected here and the OS auto-pops the dashboard.
  dnsServer.setErrorReplyCode(DNSReplyCode::NoError);
  dnsServer.start(53, "*", WiFi.softAPIP());
  captive = true;
}

// -------------------------------------------------------------------- HTTP API
static float argF(AsyncWebServerRequest* q, const char* k, float dflt) {
  if (q->hasParam(k, true))  return q->getParam(k, true)->value().toFloat();
  if (q->hasParam(k, false)) return q->getParam(k, false)->value().toFloat();
  return dflt;
}

static String argS(AsyncWebServerRequest* q, const char* k) {
  if (q->hasParam(k, true))  return q->getParam(k, true)->value();
  if (q->hasParam(k, false)) return q->getParam(k, false)->value();
  return String();
}

static void routes() {
  server.on("/", HTTP_GET, [](AsyncWebServerRequest* q) {
    AsyncWebServerResponse* res = q->beginResponse(200, "text/html",
                                                   DASHBOARD_HTML_GZ, DASHBOARD_HTML_GZ_LEN);
    res->addHeader("Content-Encoding", "gzip");
    q->send(res);
  });

  server.on("/api/state", HTTP_GET, [](AsyncWebServerRequest* q) {
    JsonDocument d;
    d["state"] = app == TESTING ? "testing" : app == FLUSHING ? "flushing" : "idle";
    d["thr"] = cal.conf_threshold;
    d["flush_ms"] = cal.flush_ms;
    d["avg_ms"] = cal.avg_ms;
    d["placeholder"] = (bool)MODEL_IS_PLACEHOLDER;
    d["fw"] = FW_VER;
    d["uptime_ms"] = millis();
    JsonObject w = d["wifi"].to<JsonObject>();
    w["mode"] = sta_mode ? "sta" : "ap";
    w["ssid"] = sta_mode ? sta_ssid : ap_ssid;
    w["ip"] = ip_str;
    if (have_result) {
      JsonDocument r;
      fillResult(r);
      d["last"] = r;
    }
    String s;
    serializeJson(d, s);
    q->send(200, "application/json", s);
  });

  server.on("/api/log", HTTP_GET, [](AsyncWebServerRequest* q) {
    if (LittleFS.exists(LOG_PATH)) q->send(LittleFS, LOG_PATH, "text/csv");
    else                           q->send(200, "text/csv", "");
  });

  server.on("/api/test", HTTP_POST, [](AsyncWebServerRequest* q) {
    bool ok = (app == IDLE);
    if (ok) startTest();
    q->send(200, "application/json", ok ? "{\"ok\":true}" : "{\"ok\":false,\"msg\":\"busy\"}");
  });

  server.on("/api/flush", HTTP_POST, [](AsyncWebServerRequest* q) {
    bool ok = (app == IDLE);
    if (ok) { pumpStart(cal.flush_ms); app = FLUSHING; pushStatus(); }
    q->send(200, "application/json", ok ? "{\"ok\":true}" : "{\"ok\":false,\"msg\":\"busy\"}");
  });

  server.on("/api/selftest", HTTP_POST, [](AsyncWebServerRequest* q) {
    Reading r;
    char why[80];
    bool ok = sensorsSelftest(r, why, sizeof why);
    JsonDocument d;
    d["ok"] = ok;
    d["why"] = why;
    String s;
    serializeJson(d, s);
    q->send(200, "application/json", s);
  });

  server.on("/api/settings", HTTP_POST, [](AsyncWebServerRequest* q) {
    cal.conf_threshold = constrain(argF(q, "thr", cal.conf_threshold), 0.0f, 0.99f);
    cal.flush_ms = (uint16_t)constrain(argF(q, "flush_ms", cal.flush_ms), 0.0f, 60000.0f);
    cal.avg_ms   = (uint16_t)constrain(argF(q, "avg_ms",   cal.avg_ms), 200.0f, 20000.0f);
    calSave();
    q->send(200, "application/json", "{\"ok\":true}");
  });

  server.on("/api/wifi", HTTP_POST, [](AsyncWebServerRequest* q) {
    String mode = argS(q, "mode");
    net_prefs.begin("amd_net", false);
    net_prefs.putBool("sta", mode == "sta");
    if (mode == "sta") {
      net_prefs.putString("ssid", argS(q, "ssid"));
      net_prefs.putString("pass", argS(q, "pass"));
    }
    net_prefs.end();
    q->send(200, "application/json", "{\"ok\":true,\"msg\":\"rebooting\"}");
    delay(300);
    ESP.restart();
  });

  server.on("/api/factory_reset", HTTP_POST, [](AsyncWebServerRequest* q) {
    calFactoryReset();
    net_prefs.begin("amd_net", false);
    net_prefs.clear();
    net_prefs.end();
    LittleFS.remove(LOG_PATH);
    q->send(200, "application/json", "{\"ok\":true,\"msg\":\"rebooting\"}");
    delay(300);
    ESP.restart();
  });

  server.onNotFound([](AsyncWebServerRequest* q) {
    // In AP mode, bounce the OS connectivity probe (and any stray URL) to the
    // dashboard — that is what makes the "Sign in to Wi-Fi" browser pop open.
    if (captive) q->redirect(String("http://") + ip_str + "/");
    else         q->send(404, "text/plain", "not found");
  });
}

static void onWsEvent(AsyncWebSocket*, AsyncWebSocketClient* c, AwsEventType type,
                      void*, uint8_t*, size_t) {
  if (type == WS_EVT_CONNECT) {
    JsonDocument d;
    readingJson(d);
    String s;
    serializeJson(d, s);
    c->text(s);
    pushStatus();
    if (have_result) pushResult();
  }
}

// ---------------------------------------------------------------------- setup
void setup() {
  Serial.begin(115200);
  delay(150);
  Serial.printf("# Aqua Milk Detect %s v%s (%s %s)\n", FW_NAME, FW_VER, __DATE__, __TIME__);
#if MODEL_IS_PLACEHOLDER
  Serial.println("# WARNING: placeholder model — every test reports Uncertain until you train.");
#endif

  dispBegin("Aqua Milk Detect");
  sensorsBegin();

  if (!LittleFS.begin(true)) Serial.println("# LittleFS mount failed (log disabled)");

  netLoad();
  netStart();
  Serial.printf("# %s  http://%s\n", sta_mode ? sta_ssid.c_str() : ap_ssid.c_str(), ip_str.c_str());

  ws.onEvent(onWsEvent);
  server.addHandler(&ws);
  routes();
  server.begin();

  tftIdle();
}

void loop() {
  if (captive) dnsServer.processNextRequest();   // service captive-portal DNS
  sensorsUpdate();
  ws.cleanupClients();

  if (app == TESTING && !avgBusy()) finishTest();
  if (app == FLUSHING && !pumpBusy()) {
    app = IDLE;
    pushStatus();
    if (have_result && last_v.uncertain) dispBig("Uncertain", AMD_AMBER, "retest");
    else tftIdle();
  }

  uint32_t now = millis();
  if (now - t_push >= 500) { t_push = now; pushReading(); }              // ~2 Hz
  if (app == IDLE && now - t_tft >= 5000) { t_tft = now; tftIdle(); }
}

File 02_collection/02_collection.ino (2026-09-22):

/*
  02_collection.ino — Aqua Milk Detect, Stage 2: capture labelled training samples.
  ESP32 DevKit (arduino-esp32 core).

  WIRELESS collection. This unit's USB-serial path is dead, so the device runs a
  Wi-Fi SoftAP and serves its own collect page. Join the AP, label the sample, hit
  Capture: the averaged row is stored on the device in /samples.csv (LittleFS) and
  downloaded over Wi-Fi. No USB needed — the board runs from its 12 V supply.

  Sensor code + calibration: libs/AquaMilkSensors (same as 01_calibration).

  CSV columns (match the trainer, web/app.js COLUMNS):
    timestamp_iso, milk_type, adulterant, level_pct, source, temp_c, ph_raw_mv,
    tds_raw_mv, turbidity_raw_mv, color_r, color_g, color_b, color_clear
  (timestamp_iso is device ms since boot — the device has no clock; the trainer
   uses the sensor columns, not the timestamp.)

  Libraries: pinned set from 01_calibration + ESP Async WebServer + Async TCP.
*/

#include <WiFi.h>
#include <DNSServer.h>
#include <LittleFS.h>
#include <ArduinoJson.h>
#include <ESPAsyncWebServer.h>

#include <sensors.h>
#include <serialio.h>          // readingJson() builds the live-view JSON
#include <display.h>

#define FW_NAME "02_collection"
#define FW_VER  "2.0.0"
#define CSV_PATH "/samples.csv"

static const char* CSV_HEADER =
  "timestamp_iso,milk_type,adulterant,level_pct,source,temp_c,ph_raw_mv,"
  "tds_raw_mv,turbidity_raw_mv,color_r,color_g,color_b,color_clear\n";

static AsyncWebServer server(80);
static DNSServer      dns;
static String         ap_ssid, ap_pass, ip_str;

enum State { IDLE, AVERAGING, FLUSHING };
static State    state = IDLE;
static uint32_t sample_count = 0;
static uint32_t t_tft = 0;

// Label stashed when a capture is requested, written when the average completes.
static char p_milk[16] = "cow", p_adu[16] = "pure", p_src[64] = "";
static int  p_lvl = 0;

// -------------------------------------------------------------------- CSV (fs)
static void csvEnsureHeader() {
  if (LittleFS.exists(CSV_PATH)) return;
  File f = LittleFS.open(CSV_PATH, FILE_WRITE);
  if (f) { f.print(CSV_HEADER); f.close(); }
}

static uint32_t csvCountRows() {
  File f = LittleFS.open(CSV_PATH, FILE_READ);
  if (!f) return 0;
  uint32_t n = 0; bool first = true;
  while (f.available()) {
    String line = f.readStringUntil('\n');
    if (!line.length()) continue;
    if (first) { first = false; continue; }      // skip header
    n++;
  }
  f.close();
  return n;
}

static void csvAppend(const AveragedSample& s) {
  File f = LittleFS.open(CSV_PATH, FILE_APPEND);
  if (!f) return;
  f.printf("%lu,%s,%s,%d,%s,%.2f,%.1f,%.1f,%.1f,%u,%u,%u,%u\n",
           (unsigned long)millis(), p_milk, p_adu, p_lvl, p_src,
           s.temp_c, s.ph_mv, s.tds_mv, s.turb_mv,
           s.r, s.g, s.b, s.c);
  f.close();
}

// Strip commas/newlines from a label so it can't break the CSV; cap the length.
static void clean(char* dst, size_t n, const String& src) {
  size_t j = 0;
  for (size_t i = 0; i < src.length() && j < n - 1; i++) {
    char c = src[i];
    if (c == ',' || c == '\n' || c == '\r') c = ' ';
    dst[j++] = c;
  }
  dst[j] = 0;
}

// ------------------------------------------------------------------------ TFT
static void updateTft() {
  const Reading& r = sensorsLatest();
  static char v_cnt[10], v_ph[12], v_tds[12], v_turb[12], v_t[12], v_col[16];
  snprintf(v_cnt,  sizeof v_cnt,  "%lu", (unsigned long)sample_count);
  snprintf(v_ph,   sizeof v_ph,   "%.0f mV", r.ph_mv);
  snprintf(v_tds,  sizeof v_tds,  "%.0f mV", r.tds_mv);
  snprintf(v_turb, sizeof v_turb, "%.0f mV", r.turb_mv);
  snprintf(v_t,    sizeof v_t,    "%.1f C", r.temp_c);
  snprintf(v_col,  sizeof v_col,  "%u/%u/%u", r.r, r.g, r.b);
  const char* status = state == AVERAGING ? "Capturing..."
                     : state == FLUSHING  ? "Flushing..." : "Wi-Fi collect page";
  const char* keys[] = { "Samples", "pH", "TDS", "Turbidity", "Temp", "Colour" };
  const char* vals[] = { v_cnt, v_ph, v_tds, v_turb, v_t, v_col };
  dispKV(status, keys, vals, 6);
}

// ------------------------------------------------------------- Wi-Fi / captive
static void netStart() {
  uint8_t mac[6]; WiFi.macAddress(mac);
  char id[5]; snprintf(id, sizeof id, "%02X%02X", mac[4], mac[5]);
  ap_ssid = String("AquaMilk-") + id;
  ap_pass = String("aqua-") + id;              // 9 chars (AP needs >= 8)
  WiFi.mode(WIFI_AP);
  WiFi.softAP(ap_ssid.c_str(), ap_pass.c_str());
  ip_str = WiFi.softAPIP().toString();         // 192.168.4.1
  dns.setErrorReplyCode(DNSReplyCode::NoError);
  dns.start(53, "*", WiFi.softAPIP());          // captive portal -> auto-open the page
}

static String argS(AsyncWebServerRequest* q, const char* k) {
  if (q->hasParam(k, true))  return q->getParam(k, true)->value();
  if (q->hasParam(k, false)) return q->getParam(k, false)->value();
  return String();
}
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

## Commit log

2026-08-17 Build Aqua Milk Detect from the spec prompts
    Three ESP32 firmwares, the GitHub Pages app, the SVM trainer and CI, per
    PROJECT_CONTEXT.md and docs/prompts/.
    - libs/AquaMilkSensors: one implementation of the sensor stack (pH, TDS,
    turbidity, TCS34725, DS18B20, HX711), NVS calibration, trimmed averaging,
    pump control and ST7735 display, shared by all three sketches via
    arduino-cli --libraries.
    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
    [SYNTHETIC_sample.csv]
2026-08-17 Fix silent-failure paths found by running both UIs in a browser
    Served the app and the device dashboard locally and drove them from the
    console. Three real defects, all cases where a failed fetch left a UI that
    looked broken with no explanation:
    - dashboard.html: the boot fetch of /api/state had no .catch, so one failed
    request (device rebooting, Wi-Fi dropped mid-load) threw and aborted init --
    no settings values, no placeholder banner, no tables. It now degrades to
    'No device - cannot reach the tester' with the bars and history still drawn.
    loadLog() gained the same guard.
    - web/app.css: esp-web-install-button has no shadow root until the custom
    element upgrades, so all three sl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
2026-08-17 Vendor esp-web-tools, merge the two workflows, stop committing binaries
    The live Flash page had no install buttons. Root cause: the pinned CDN URL
    esp-web-tools@10.0.4 does not exist -- that version was never published, so the
    module 404'd in every browser and only the fallback notice rendered.
    - web/vendor/esp-web-tools/ now holds v10.4.0's bundled dist/web plus its
    Apache-2.0 LICENSE, and index.html loads it locally. No CDN to 404, to go
    offline, or to be blocked by an extension. Verified the custom element
    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
2026-08-17 Liquid-glass UI on all three surfaces, plus a ponytail pass on the firmware
    UI. The old flat cards read as cheap because backdrop-filter had nothing behind
    it to blur. Fixed at the root: an aurora backdrop of four slowly drifting colour
    fields on near-black, blurred 70px, with SVG grain at 3.5% so the gradients do
    not band. Everything above it is now one glass material -- translucent fill,
    backdrop blur + saturate, 1px stroke, inset rim light, and a 118 degree specular
    sweep. Cursor position feeds --mx/--my so each panel paints a specular bloom
    under the pointer, the web equivalent of SwiftUI's .interactive().
    - web/: capsule nav floating inset from the edges, 30px glass cards, tinted
    gla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
    [01_calibration.ino, 02_collection.ino, 03_deployment.ino]
2026-08-17 Refine the glass: real edge thickness, optical type, bento hierarchy
    Second pass on the UI, all craft-level:
    - Panels get glass thickness -- a bright 0.5px top hairline, a dark 0.5px
    bottom one and a 0.5px surround, replacing 1px borders that render chunky on
    2x/3x displays. Wide soft drop shadows only, no hard offsets. Added a
    backdrop vignette so the corners stay calm.
    - Optical typography: hero tracking tightens as it scales (86px at -3px),
    text-wrap balance on headings and pretty on body copy, measure capped at
    56ch, uppercase micro-labels at 0.09-0.14em for keys and table headers,
    tabular numerals on every readout so digits stop jittering.
    - Structure: accent eyebrows above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
2026-08-17 Fix the layout bugs the screenshot exposed, centre the hero, add real motion
    Your screenshot showed four separate problems, all now traced to a cause:
    - The 2x2 grid never lined up because .card + .card applied a 16px stacking
    margin INSIDE the grid, pushing every tile after the first down and leaving
    rows misaligned with random heights. Scoped it to normal flow only; all four
    tiles are now one uniform 178px block.
    - Dropped the bento span. It left Run orphaned on a row of its own, which read
    as a bug rather than a focal point.
    - The hero was left-aligned in a 1040px column on a wide display, so the
    buttons looked off-centre. The whole hero is centred now.
    - 'Flash a device' rende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
2026-08-17 Drop the dashboard.h staleness gate; CI regenerates it anyway
    The gate compared the committed header against one regenerated on the runner,
    which requires byte-identical gzip output across machines. zlib makes no such
    guarantee between versions, so a correct header failed the build twice.
    CI regenerates the header before every compile, so a stale committed copy
    cannot reach a binary. The committed copy only exists so a local arduino-cli
    compile works without running Python first.
2026-08-17 Give the glass something to refract
    The panels read as flat tinted boxes for a reason that is optical, not stylistic:
    blurring a smooth gradient returns the same smooth gradient. The aurora had no
    detail in it, so backdrop-filter had nothing to smear and every card came out as
    a solid wash of whatever colour sat behind it. Apple's glass always sits over
    structured content -- text, icons, lists scrolling underneath.
    So there is now a mesh layer behind the glass: a fine ruled grid plus hard-edged
    motes drifting upward. Crisp where you see it directly, smeared into soft bands
    under a panel. That contrast is what registers as glass.
    The fill also had to come down. It was .14/.05, thick enough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
2026-08-17 Rebuild the material from the reference images
    Studied what is actually common to real liquid glass, and my version had none of it:
    - The fill is almost nothing. In every Apple example the panel is essentially
    transparent; the material is the blur and the rim. Mine sat at 8.5% white,
    which is thick enough to tint rather than transmit. Now 4.5%.
    - The rim does the work, and it VARIES around the shape: near-white where the
    light strikes, fading to nothing across the middle, catching again on the
    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
2026-08-17 Bigger tile titles beside the icon, a theme toggle, and a legible accent
    - Tile heading moves onto one row with its icon and grows 18px -> 23px. Stacked
    under a badge it read as a caption rather than a title.
    - Accent teal is unreadable as small text or a thin stroke on a teal-lit glass
    panel: it sits at nearly the same luminance as its own background, which is
    why the icons vanished. Anything that has to be READ now uses --accent-ink,
    a far brighter cyan in dark (15.5:1 against the page) and a deep teal in
    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
2026-08-17 Darken the dark theme
    Ground drops from #05070A to #030406, and the colour washes come back from .45
    to .26 opacity — they were flooding the page rather than lighting the glass, so
    the whole thing sat at mid-teal instead of reading as dark. Vignette deepened to
    compensate at the edges, ribbons eased from 10% to 8.5% white.
    The glass itself is unchanged: with a darker ground behind it, the same 4.5%
    fill and brightness(1.08) now read as a pane catching light rather than a tinted
    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
2026-08-17 Bring the dashboard's form controls into the design language
    The settings panel was still native: black boxes with a browser select, plain
    14px labels and a default range slider, sitting inside glass cards.
    - Inputs and the select are recessed glass troughs now — hairline stroke, 14px
    radius, 46px tap target, blur, and an accent focus ring.
    - The select loses its native chrome for a drawn chevron.
    - Labels match the app: 11px uppercase at 0.09em, muted.
    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
2026-08-17 Replace the native select with a glass listbox
    A native select's option popup is OS chrome: it cannot be blurred, rounded or
    tinted, which is why it kept opening as a white slab with a blue highlight in
    the middle of the glass. The only fix is to stop using one.
    The control is rebuilt from elements we own: a glass trigger with a chevron that
    flips, and a popup with the same material as the cards — 26px blur, 18px radius,
    hairline, and a small spring on open. The selected row is marked with a glowing
    dot rather than a checkmark, so it reads at a glance.
    It stays a real control: aria-haspopup/expanded on the trigger, role=listbox and
    role=option with aria-selected, arrow-key navigation, En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
2026-08-17 Make the open menu occlude what is under it
    Two separate causes for the overlapped look:
    1. The popup used card transparency, so the SSID label underneath read straight
    through the options. A floating menu has to be a thick material — it is now
    90% opaque over a 30px blur (94% in light), with a deeper shadow and hairline
    dividers between rows.
    2. Even opaque, it was painted UNDER the next card. Every .card sets
    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
2026-08-18 Replace the mobile nav strip with a dropdown, and make the scale fluid
    The nav's five links do not fit beside the wordmark below ~720px, and both
    obvious answers were wrong: wrapping grew the sticky capsule to 190px on a
    320px phone, and a horizontal scroll strip clipped "Flash" to "lash" while
    relying on a gesture nobody performs on a nav. They are now a dropdown, using
    the same glass listbox the device dashboard already has for its Wi-Fi mode.
    The markup does not change between modes, so the same five anchors are the
    desktop row and the phone menu, and the nav still works with the script
    blocked.
    Spacing, radii and type moved onto a clamp() scale interpolating between a
    360px phone and a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
2026-09-20 Switch pump to 3.3 V relay; add TFT rotation, captive portal, web controls
    Firmware / shared lib:
    - Pump driver now drives GPIO25 as a plain digital output (pinMode + digitalWrite)
    instead of LEDC PWM — a relay is a mechanical switch and chatters under PWM.
    PUMP_ACTIVE_LOW defaults to false for this build's active-HIGH relay module.
    - TFT: fix the ST7735 edge-offset glitch via a configurable panel variant
    (AMD_TFT_INITR) + optional col/row nudge; add software display rotation
    (dispSetRotation/dispRotation) persisted to NVS; vertically centre the verdict
    and tidy the header so layouts fill the screen in any orientation.
    - Rotation is settable from the on-device Settings menu (depl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
    [body.stl, dry_lid.stl, enclosure-lab.scad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]
2026-09-20 Align Flash install buttons to the card bottom
    Collection's blurb is one line while Calibration and Deployment wrap to two, so
    its Install button rode higher. Make each #flash card a flex column and pin the
    esp-web-install-button with margin-top:auto so all three align regardless of text
    length.
2026-09-21 Move TFT DC/RST off boot-strapping pins so USB flashing works
    DC was on GPIO2 and RST on GPIO15 — both ESP32 boot-strapping pins. With the
    display soldered to them, the chip is held out of boot/download at reset: the
    USB-serial port enumerates but esptool gets no response ("failed to initialize"
    / no serial data), and no button sequence helps. Move DC->GPIO13 and RST->GPIO14
    (both free, non-strapping) so the board flashes over USB every time with no
    desoldering. Only pins.h + wiring docs change; display.cpp reads the macros.
2026-09-21 Revert TFT DC/RST to GPIO2/15 to match the soldered board
    The board's display is physically soldered to DC=GPIO2 / RST=GPIO15. The earlier
    move to GPIO13/14 made the flashed firmware drive the wrong pins, so the panel got
    no DC/RST and showed white static. These are boot-strapping pins, so in-place USB
    flashing is blocked — the working method is to pull the socketed DevKit, flash it
    bare, and reseat. Documented that in the pin notes instead of moving the pins.
2026-09-21 Default TFT rotation to 1 for this build's panel mounting
    The panel renders sideways at rotation 0 (header on the right edge, text reading
    bottom-to-top). Set AMD_TFT_ROTATION default to 1 so a fresh flash comes up with
    the header at the top. Runtime dispSetRotation()/the rotation control still override
    it; flip the default to 3 if a unit reads upside-down.
2026-09-21 Remove TTP223 touch pad; control the deployment device from the dashboard only
    The touch pad is gone from the build, so strip all of its firmware: the gesture
    reader, the on-screen menu, and deep sleep (nothing was left to wake it). Every
    action it offered already exists as a Wi-Fi dashboard endpoint — Run test
    (/api/test -> startTest), Flush, Tare, Re-check calibration (/api/selftest),
    Settings, Wi-Fi, Factory reset — so the dashboard is now the sole control surface.
    GPIO27 is freed in pins.h. Calibration/collection never used the pad.
    [03_deployment.ino]
2026-09-21 Docs: drop TTP223 / gestures, describe browser-only deployment control
    Firmware no longer uses the touch pad, so update the wiring/BOM/pin tables and the
    interaction section: GPIO27 is free, and the deployment device is driven entirely
    from the Wi-Fi dashboard (Run test / Flush / Tare / Re-check cal / Settings / Wi-Fi /
    Factory reset). No on-device menu or deep sleep.
2026-09-22 Collection over Wi-Fi: SoftAP + served page, on-device CSV (USB serial is dead)
    This unit's USB-serial link is physically dead when the DevKit is seated, so
    collection can't stream to the browser. Convert 02_collection to a Wi-Fi SoftAP:
    it serves its own collect page (label + live values + Capture/Flush/Tare), averages
    a sample on Capture, stores it to /samples.csv on LittleFS, and serves the CSV for
    download over Wi-Fi. Weight in grams (density_g) is shown live and on the TFT and
    is a CSV column. No USB needed — the board runs from 12 V. CSV columns match the
    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
2026-09-22 Add HX711 raw-count diagnostic to the collection page
    Weight reads a constant 0. Expose the raw HX711 count and a ready-read counter
    (sensorsScaleRaw/sensorsScaleReads) in the live JSON and show them on the Wi-Fi
    collect page. If "reads" never climbs, the HX711 is not signalling ready
    (power/DOUT); if it climbs but "raw" doesn't move under load, it's the load cell
    or mechanics. Diagnostic only — no change to sensing or the CSV schema.
    [02_collection.ino]
2026-09-22 Trainer: drop the density/load-cell feature (8 features now)
    The load cell is removed from the build, so density is no longer a model input.
    utils.FEATURES drops "density", raw_to_features drops the specific-gravity transform
    (no more chamber_ml), RAW_COLUMNS no longer requires density_g (old CSVs with a
    density_g column still load — it's ignored). train.py loses --chamber-ml and forces
    UTF-8 stdout so it runs on the Windows console. Verified end to end on synthetic data.
2026-09-22 Remove the load cell / density feature from the firmware
    The load cell is fried and out of the build, so density/weight is gone end to end:
    features.h drops F_DENSITY (FEATURE_COUNT 9 -> 8, temp/colour reindex); sensors.*
    lose the HX711 driver, density_g/ok_scale, specificGravity, calTare and
    calDensitySpan; pins.h frees GPIO16/17; serialio drops dens/sg; the placeholder
    model.h/scaler.h are now 8-wide; and the three sketches drop the weight readouts,
    the CSV density_g column, and the tare/density-calibrate commands. Matches the
    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
2026-09-22 Enclosure (working box): full rewrite, no load cell
    Cup now stands on a fixed printed pedestal + platform (no load cell, no riser, no
    HX711). Drop all weighing/tare/density rationale; the pedestal stays because its real
    job is lifting the short probes into the milk. Also fix now-stale bits: no TTP223 touch
    pad (browser control), and the relay note (wiring.md is correct; 3.3 V relay is active-HIGH).
2026-09-22 Enclosure (tower): rewrite for a fixed cup platform, no load cell
    Replace the load-cell/weighing/tare/datum rules with a fixed platform bolted to the
    shelf pedestal; the column still lifts only to clear the probes. Drop the touch-pad and
    single-tap references (browser control), and the PETG 'creeps under a bolted load cell' note.
2026-09-22 Enclosure (bench): rewrite for a fixed cup platform, no load cell
    Cup settles on the fixed platform (no load cell, no riser, no weighing/density);
    run tests from the dashboard, not a touch pad. Drop the load cell from the parts list.
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2026-09-23 Deployment: drop load-cell/weight UI, refresh smoke-test model
    Remove all weight / load-cell / specific-gravity remnants from Stage 3:
    - dashboard.html: Tare button + /api/tare handler, "Density" feature label,
    "Specific gravity" and "Weight" reading rows, and the SG column in the
    history table, CSV export and log parser. Fixes two latent bugs along the
    way -- the 9-vs-8 feature-label misalignment, and the 8-vs-7 log-column
    offset that made the SG cell display temperature.
    - 03_deployment.ino: strip stale /api/tare, dens, density and tare mentions
    from the header docs.
    - Regenerate dashboard.h.
    Refresh model.h / scaler.h from the current training set. NOTE: this is a
    smoke-test mo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
    [03_deployment.ino]
